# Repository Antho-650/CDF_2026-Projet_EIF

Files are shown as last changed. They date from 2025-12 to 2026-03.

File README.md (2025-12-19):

# CDF 2026 - Projet EIF

Dépôt officiel pour la participation à la Coupe de France de Robotique 2026.

## Documents et Suivi

Le suivi des achats (Excel/Google Sheets) et les documents administratifs sont sur le Google Drive du projet : https://drive.google.com/drive/u/1/folders/1xHnVBchuZF8TSyvHd5yfe0Ny8L7n_gqj

## Structure du dépôt

- **documents/** : Documents généraux du projet (spécifications, règlement, etc.)
- **robot_principal/** : Fichiers du robot principal
  - **electronique/** : Cartes électroniques (haut niveau, base mobile, actionneurs)
  - **mecanique/** : Conception mécanique (assemblage complet et sous-ensembles)
  - **code/** : Code embarqué (STM32) et code haut niveau (Raspberry Pi)
- **balises/** : Système de balises (électronique, code, mécanique)
- **pami_ninja/** : PAMI Ninja (électronique, mécanique, code)
- **pami_statique/** : PAMI Statique pour fin de match (électronique, mécanique, code)

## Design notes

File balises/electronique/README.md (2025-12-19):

# Balises - Électronique

Fichiers KiCad pour les cartes électroniques des balises de détection.

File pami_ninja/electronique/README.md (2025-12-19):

# PAMI Ninja - Électronique

Fichiers KiCad pour la carte électronique du PAMI Ninja.

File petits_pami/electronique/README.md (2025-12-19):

# PAMI Statique - Électronique

Fichiers KiCad pour la carte électronique du PAMI Statique (fin de match).

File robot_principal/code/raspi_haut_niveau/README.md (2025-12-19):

# Code Raspberry Pi - Haut Niveau

Code Python pour le Raspberry Pi (stratégie, intelligence artificielle, communication).

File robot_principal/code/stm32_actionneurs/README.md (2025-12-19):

# Code STM32 - Actionneurs

Code embarqué STM32CubeIDE pour le contrôle des actionneurs.

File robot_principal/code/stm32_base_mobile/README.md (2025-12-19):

# Code STM32 - Base Mobile

Code embarqué STM32CubeIDE pour le contrôle de la base mobile.

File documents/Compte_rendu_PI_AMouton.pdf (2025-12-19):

# Compte Rendu Projet Ingénieur

## Réalisation d’un robot pour la coupe de France de robotique

## Etudiant Ingénieur : Albin Mouton

## Tuteur de Projet : Xavier Redon

## Responsable UE Projet : Florian Chevalier

# Introduction

## La Compétition

La coupe de France de robotique est une compétition nationale qui, cette année, fête ses 30 ans.
Elle réunit une centaine d'équipes chaque année en mai, à la Roche-Sur-Yon.
Le règlement de la compétition est publié tous les ans en septembre. J’ai pu m’appuyer sur celui-ci lors de la rédaction de mon cahier des charges.
Les équipes doivent alors concevoir un robot de toute pièce, afin de remporter un maximum de points.
Les robots participent à des matchs en 1 contre 1. Deux équipes tentent en même temps de réaliser un maximum d’actions.
Le thème de cette année est “Coloniser Mars”. Les robots sont dans un scénario de “ferme spatiale” avec plusieurs objectifs :
- Récupérer des plantes, les mettre dans des cache-pots, et venir les trier dans des zones de dépôt ;
- Orienter des panneaux solaires ;
- Faire entrer en contact les PAMI avec les plantes récupérées ;
- Prédire le plus précisément son score.

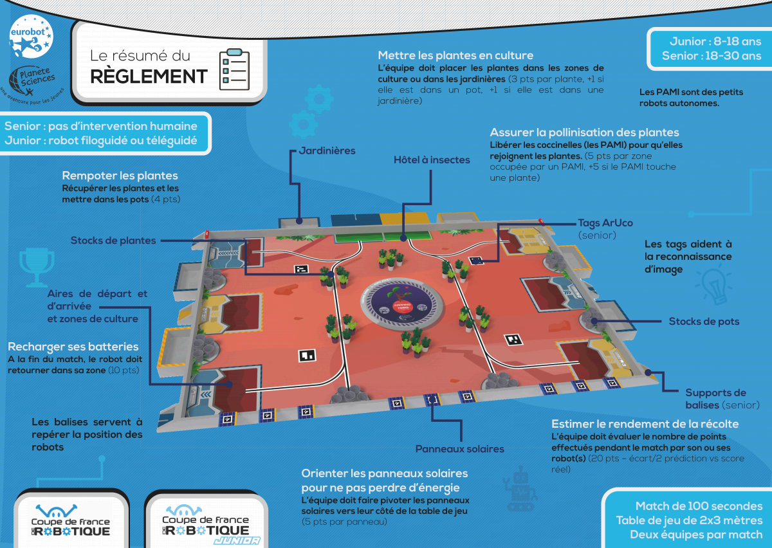
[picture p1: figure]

Figure 1. Illustration simplifiée du règlement

Les robots doivent respecter certaines règles :
- Être plus petit qu’un cube de 30x30x30 cm ;
- Etre autonome sur l’ensemble du temps de jeu (100 secondes) ;
- Démarrer en tirant une ficelle ;
- Ne pas entrer en contact avec le robot adverse, ou endommager le matériel de jeu ;
- Etre équipé d’un bouton d’arrêt d’urgence ;
- Les batteries doivent respecter des consignes de sécurité.

Sur place, les robots doivent d’abord passer 2 homologations, effectuer au maximum 5 matchs de placement, avant de potentiellement participer à l’arbre de tournoi de la phase finale.
Les 2 meilleures équipes obtiennent le droit de participer à la coupe d’Europe qui se déroule à la Roche sur Yon le même weekend.

## L’Équipe

Cette année, j’ai la chance de participer à la coupe de France de Robotique avec une dizaine d’élèves ingénieurs membres de Robotech. Le club de robotique de l’école, Robotech, a déjà participé à cette compétition l’année passée. La participation du Club après plusieurs années d’absence nous a permis de nous rendre compte du réel défi que représentait la coupe, de nous positionner face à nos adversaires et surtout d’évaluer nos choix de conception grâce à une mise en conditions réelle de notre robot.
C’est ainsi qu’aidé par le bureau du club de robotique de l’école, j’ai pu mettre en œuvre les leçons apprises l’an passé et tirer profit de la conception précédente de notre Robot.

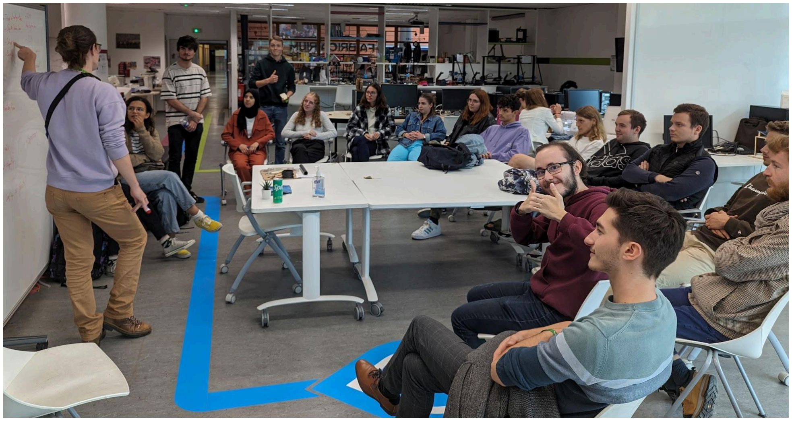
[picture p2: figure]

Figure 2. Réunion de présentation du projet aux membres du club

# Cahier des charges

Ci-dessous vous trouverez le cahier des charges initial commenté afin évaluer l’état d’avancement du projet.
( ✅ : objectif complété, ➖ objectif partiellement réalisé (avec un commentaire), ❌ objectif non-atteint)
- Conception du robot principal | ➖
- Conception/Intégration d’un ou plusieurs lecteurs RFID. (réorienté en IA)➖
■ Conception du nœud ROS2 de lecture du tag. | ✅
- Conception d’une base roulante | (Partiellement assemblée) | ➖
■ Base roulante dont la projection a un périmètre
est inférieure à 120 cm | ✅
■ Conception d’un contrôleur de moteur BLDC | ➖
- Asservi (capteur d’orientation magnétique)
en Field Orientation Control (FOC)
(Performance Insuffisante ) ➖
- Base STM32 | ✅
- Communication CAN, UART & USB | ✅
- Alimentation batterie Li-Po 6S | ✅
- Support de moteurs jusqu’à ~30A | ✅
■ Conception d’un système d'entraînement des roues par BLDC | ✅
- Conception d’actionneurs de saisie | ❌
■ Conception mécanique des actionneurs | (en cours) | ➖
■ Développement de nouveaux noeuds ROS2 adaptés aux nouveaux
actionneurs | ❌
- Correction de la carte mère actuelle du robot | ✅
■ Développement d’un driver pour permettre d’interfacer les IMU | ❌
- Amélioration du système de Path Planning | ❌
- Amélioration du système de calcul de points | ❌
- Conception des PAMI | ➖
- Conception d’une carte mère | ✅
■ Taille la plus petite possible ~25cm² | ✅
■ Contrôle de 2 moteurs DC | ✅
■ Des emplacements pour des vis afin que le PCB soit un châssis ✅
■ Des GPIO permettant une modularité sur les actionneurs | ✅
■ Capteurs de couleur pour permettre un suivi de ligne | ✅
■ Bouton d’arrêt d’urgence (besoin de modifier la carte d’extension pour
soutien mécanique) | ➖
■ Communication Radio (bandes 2.4 GHz & 5 GHz proscrites car
surchargées, donc probablement du sub-GHz ) | ✅
- Conception d’une clé USB pour interfacer les PAMI via cette bande radio
choisie | ✅
- Communication avec une tour de supervision selon des objectifs transmis par
le robot principal | (en cours) | ➖

# Cahier des spécifications

Ci-dessous se trouve le cahier des spécifications communiqué au tuteur.

## Description des éléments

### Tour de supervision

La tour de supervision est placée dans une zone dédiée du terrain. Elle peut être suffisamment haute pour permettre à une caméra d'y être installée. Cette caméra sera une caméra 4K avec un FOV de 110° pour voir l’ensemble du terrain.
Sur cette tour se trouve également un micro-ordinateur (NVidia Jetson), venant interpréter les valeurs de la caméra à l’aide de la bibliothèque OpenCV.
ROS2 sera également installé pour permettre de débugger le robot principal et la tour simultanément si tous sont sur un même réseau local.

### Carte de contrôle de moteur BLDC

Basé sur un STM32F303 et un DRV8323, le contrôleur peut commuter jusqu'à 36V à ~30A pour venir alimenter un moteur à courant continu sans balai (BLDC).
Le PCB est un PCB 4 couches (70 um - 17.5 um - 17.5 um - 70 um)
Il dispose d'un port USB, de 2 ports série et d'un port CAN pour venir changer la consigne. Un encodeur (incrémental ou positionnel) peut venir être connecté. Le moteur pourra être asservi en vitesse ou en position.
La carte sera auto-alimentée (générera ses rails 5V et 3.3V) à partir de la tension de la batterie.

Un identifiant peut être programmé dans la mémoire non volatile via le port USB. Cet identifiant définit les adresses à lire sur le bus CAN.

Un nœud ROS2 doit être écrit pour communiquer les consignes de vitesse avec les contrôleurs via le bus CAN. Celui-ci traduit également une commande de vitesse dans un repère orthonormé en les vitesses équivalentes des 3 moteurs placés en Triangle.

Le firmware de la carte mère doit être modifié pour permettre une communication CAN.

### Encodeur absolu magnétique

Cette carte est un simple support pour l'encodeur magnétique MT6701, capable de communiquer en I2C ou en incrémental (UVW). Un connecteur JST-SH permettra de l’interfacer.

Le PCB est un PCB 2 couches (35 um - 35 um, sans contrôle d’impédance des lignes)

### Clé USB Radio

Pour communiquer avec les PAMI et ne pas modifier en profondeur la carte mère du robot principal, un STM32 vient interfacer un port USB-A et une puce CC1101 pour permettre à un ordinateur la communication 865 MHz. Un connecteur d’antenne SMA permettra de pouvoir expérimenter avec différentes antennes.

Le PCB est un PCB 4 couches (35 um - 17.5 um - 17.5 um - 35 um)

Le STM32 apparaît comme un port série virtuel, les paquets émis en UART seront émis en radio et vice-versa.
Cette clé servira également sur la tour de supervision

### PAMI

La taille du PAMI doit être inférieure à 8x8x8cm.

Le PCB principal est un PCB 4 couches (35 um - 17.5 um - 17.5 um - 35 um)
Les PCB des capteurs de distance et d’extension seront des PCB 2 couches (35 um - 35 um, sans contrôle d’impédance)

Basé sur un STM32F103, les PAMI sont dotés de 2 contrôleurs de moteurs DRV8837, un contrôleur de charge de batterie Li-Po/Li-Ion (MCP73831), un buck boost 2.5V-6V -> 3.3V (TPS63051), et un accéléromètre gyroscope (LSM6DS3). Il peut être alimenté par des piles AA ou une batterie.
3 sorties de puissance sont disponibles (ex : pour alimenter un électro-aimant directement avec la batterie).

Un second PCB sert également à venir intégrer des connecteurs d'extension, ainsi qu’un tag ARUCO, qui pourront être lu par une caméra de supervision pour obtenir la position du PAMI.

Trois PCB supportant des capteurs de distance VL53L3 seront soudés verticalement entre le PCB principal et le PCB secondaire.

Les PAMI sont dépendants des informations de positionnement qui leur seront envoyées via la tour de supervision. Une fois que le robot principal aura démarré, un signal leur sera envoyé. Cela déclenche un timer de 90 secondes, qui, une fois dépassé, démarre le programme de déplacement des PAMI. Les PAMi vont à un objectif aux coordonnées prédéfinies en se basant sur les informations de position renvoyées par la caméra, mais peuvent s’arrêter si un obstacle est détecté devant eux.

# Organisation et gestion de projet

## Communication avec le tuteur projet

Pour permettre un suivi du projet par mon tuteur, un Wiki a été mis en place. Dans celui-ci j’ai pu documenter toutes mes avancées, ainsi que donner les premières documentations techniques.
Ce wiki est disponible ici (https://projets-se.plil.fr/mediawiki/index.php/SE5_2023/2024_P2) Ce système de documentation m’a permis de rédiger les premières documentations, poser le contexte, mais aussi d’évaluer la progression hebdomadaire de mon projet.

J’ai également pu rentrer en contact avec M. Redon afin de lui soumettre les problématiques que j’ai pu rencontrer :
- Du matériel a pu être commandé afin de corriger certaines cartes ;
- Nous avons pu discuter d’algorithmes de commande de moteur afin d’optimiser le contrôle de celui-ci ;
- J’ai pu exprimer et formaliser les points méritaient son attention, ce qui m’a permis de synthétiser les problèmes pour qu’ensemble nous trouvions des solutions.

## Gestion financière

Le matériel a été acheté par la trésorerie du club. Un rapport complet des dépenses a été effectué. Cependant, des fonds ont dû être levés pour financer de nouvelles générations de PCB. Pour cela, j’ai pu travailler en Freelance pour le club auprès d’un ancien étudiant de Polytech Lille.
J’ai pu concevoir une carte permettant de contrôler un moteur pas à pas via un port USB, ainsi que diverses entrées sorties. Cette carte dispose également d’un Hub USB pour permettre de venir brancher une caméra et d’être reconnue par le PC hôte. La carte est contrôlée en GCode, avec la même bibliothèque que j’ai écrite pour les projets.
Cela a permis de ne pas faire perdre d’argent au club tout en finançant le projet de la coupe de France de Robotique.

## Gestion d’équipe

Dans le cadre du projet, j’ai été accompagné par les membres de Robotech, club de robotique de Polytech-Lille. En ma qualité de chef de projet, j’ai pu gérer cette équipe pour atteindre les objectifs listés plus haut dans la partie technique.
Pour se faire, j’ai pu organiser des réunions d’avancement hebdomadaires (tous les mercredis midis), ainsi que des séances de travail (tous les mercredis soir). Dans ces séances, j’étais disponible pour investiguer les obstacles qu’ils rencontraient, former les nouveaux membres, débattre et trancher sur les solutions techniques proposées.

J’ai pu mettre en place différents outils afin d’organiser nos travaux :
- Un serveur discord, permettant la discussion organisée par salons tournés vers des sous parties du projets. Cela avait pour but de laisser une trace simple et informelle des échanges, ainsi que de pouvoir noter les éléments de réponses et astuces qui n’auraient pas eu place dans ce rapport
- Un répertoire Gitlab, pour permettre la mise en commun de code, car la perte de travaux est monnaie courante, comme les membres utilisent leur matériel personnel, et qu’il est pertinent de pouvoir travailler à plusieurs sur un même sous-ensemble du projet.
- Une équipe Fusion-360, pour permettre aux élèves ingénieurs en spécialité mécanique de travailler en commun, d’exporter la nomenclature de tout ou partie du projet, et de faire du versioning sur des pièces ou des assemblages ;
- Un ordinateur de test dans la même configuration que le robot, afin de tester dans des conditions proches, le code qui a pu être développé ;
- Des disques dur bootable & live, sous Linux (Ubuntu 22.04) où ROS2 est installé, pour pouvoir permettre un développement aux personnes sous des machines Windows.

J’ai pu gérer la motivation d’une équipe, encourager l’évolution de chacun, et conseiller leurs décisions afin qu’ils puissent obtenir un résultat tangible.

J’ai également défini une politique d’évaluation de la valeur du temps de chacun passé sur une tâche. En effet, j’ai imposé à chaque membre de se définir un équivalent coût-horaire. Si, pour mettre en place une solution, une option permettait d’économiser N heures de travail coûtait moins que N*(coût horaire auto-défini pour la personne), alors nous investissions pour économiser du temps.
Cette politique est due au fait que le temps disponible de chacun par semaine est réduit (au minimum 2h, au maximum ~8h). De plus, cela a permis à certains membres d’explorer de nouveaux outils.

## Gestion du temps

On peut comparer le diagramme de Gantt initial et le diagramme actualisé.

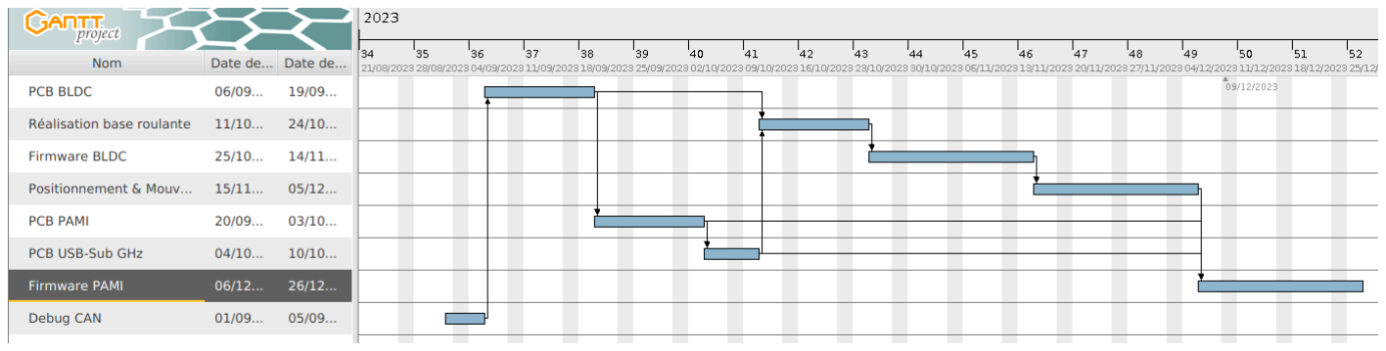
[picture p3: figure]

Figure 3. Gantt prévisionnel

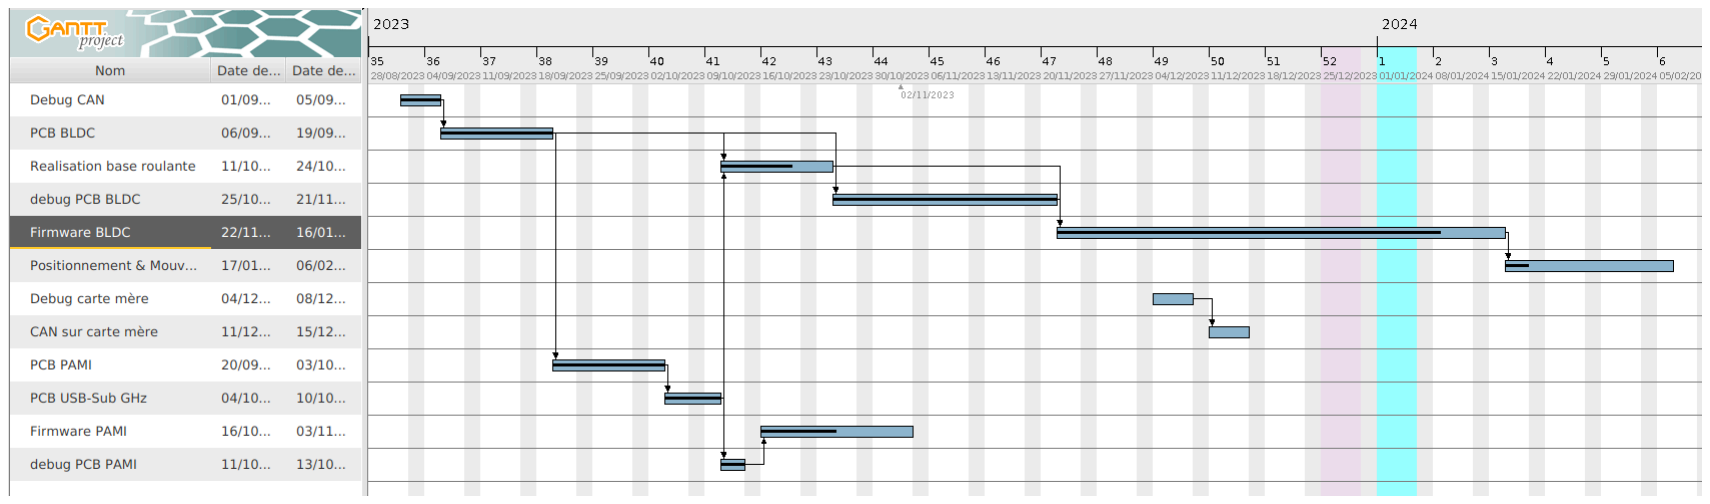
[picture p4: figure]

Figure 4. Gantt mis à jour

J’ai pris plus de temps qu’estimé à cause de problèmes techniques rencontrés. En effet, j’ai fait des erreurs sur les cartes qui m’ont pris du temps. Ces périodes de debug (que j’ai rajouté) m’ont fait perdre du temps. Suite à des problèmes de santé, je n’ai pas pu consacrer la semaine 01 de 2024, ce qui m’a également retardé.

# Carte de Contrôle moteur

## Contexte général

### La Coupe de France de Robotique 2023

Cependant, au cours du projet, nous avons réalisé que la motorisation de notre robot était insuffisante. Elle était basée sur des moteurs à courant continu avec balais (Moteurs DC), qui, par le biais de réducteurs, venaient faire tourner des roues Mecanum.
Cette architecture permettait un déplacement latéral du robot, mais a pu engendrer certains problèmes :
- 4 roues Mecanum placées comme sur une voiture sont requises.
- Pour que ces 4 roues soient en contact simultanément avec le sol, il faut un système de suspension :
■ Trop encombrant
■ Trop complexe (Il faut éviter autant de pièce possible en micromécanique)
■ Trop cher (Plusieurs centaines d’euros)
- Les 4 roues, avec leur réducteur réduisent grandement la surface au sol disponible pour les actionneurs. En effet, seule la moitié de cette surface permettait l’installation d’un bras manipulateur.
- Les moteurs DC disponibles dans le commerce, de petite taille, tournent souvent très (trop) vite mais développent un couple très faible. Un réducteur important est nécessaire (environ 1:200)
- Réducteur Planétaire : doit être réalisé sur mesure (très cher)
- Réducteur à vis : peu volumineux, abordable, et non réversible, mais souvent fragile (plusieurs casses le jour de la compétition)
- Réducteur à roue dentées : Plus volumineux, mais fragile, difficile à se procurer
- Réducteur à poulie : sur mesure, mais peut être réalisé au sein de l’école : chronophage
- Complexité de câblage
- La carte de contrôle de moteur DC faisait 10x10cm
- Elle supportait 6 moteurs avec leurs encodeurs (soit 6x(2+4) câbles) De plus, nous avons constaté que notre configuration (moteur DC) n’était pas utilisée par les équipes qui performaient le mieux.

## Hardware

### Choix de composants

Le coeur de la carte est un STM32F303BT
Celui-ci a été choisi de par :
- Son unité de calcul flottant : capable de faires des opération mathématiques sur des nombres à virgules, important pour pouvoir faire des calculs de PID ;
- Sa connectivité USB & CAN, la première pour pouvoir débugger et la deuxième pour la simplicité de câblage ;
- Les autres cartes du robot utilisent également des STM32. Toutes les fonctions implémentées sur un projet peuvent être portées sur un autre (par exemple le Parser GCode est la même bibliothèque que j’ai écrite pour les cartes de contrôleur moteur DC & BLDC).

Ce microcontrôleur commute les 6 MOSFETs nécessaires au contrôle du moteur par le biais d’un contrôleur DRV8323 de chez Texas Instruments.
Il inclut :
- Des amplificateurs pour la mesure de courant ;
- Un mécanisme de “charge pump” pour commuter les MOSFETs à haute tension ;
- Différentes sécurités (sur-courant, sous-tension, sur-tension entre le drain et la source lors de la commutation, …).
Pour permettre un asservissement en position, un encodeur magnétique 14 bits peut être connecté via un port JST-SH8. Celui-ci s’interface en I2C (débit relativement bas), ainsi qu’en UVW (impulsions successives par cran, plus rapide que la communication I2C)

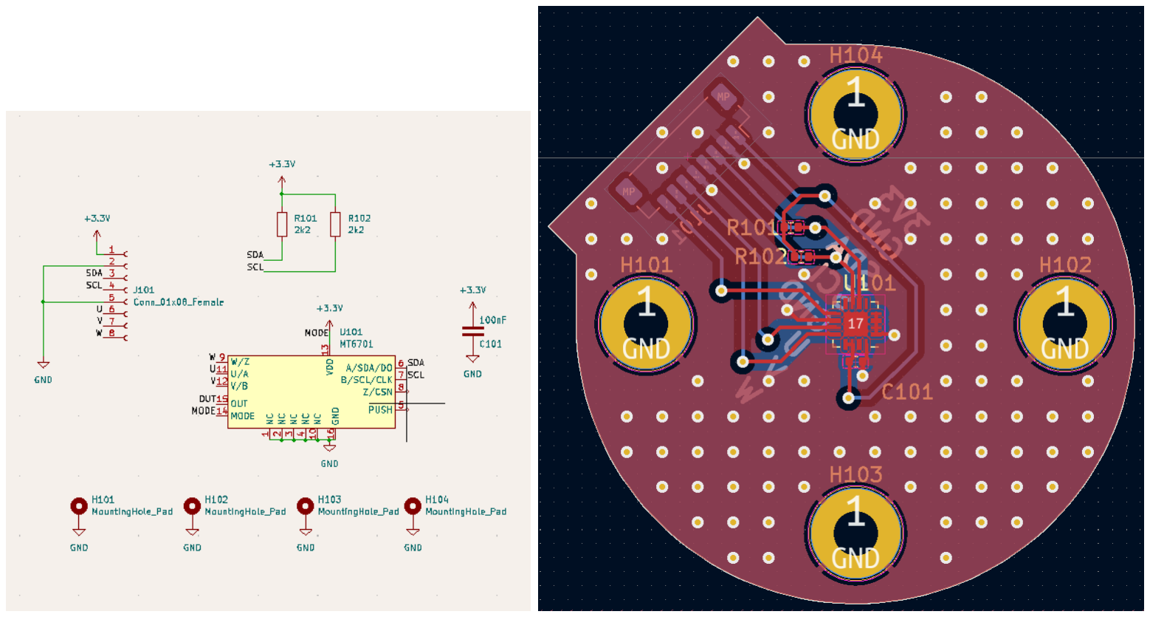
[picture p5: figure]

Figure 6. Schéma et PCB de l’encodeur

### Principe de fonctionnement

La contrôle peut se faire via port série (De nombreux ports série sont disponibles sur la carte mère) à 115200 bauds, 8b1n, ou port série émulé sur un port USB mini-B.

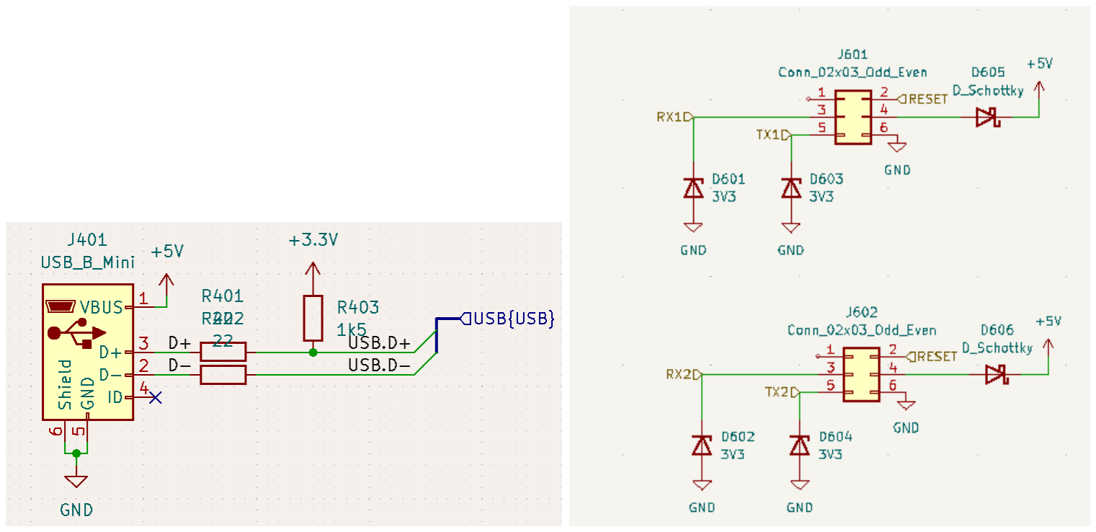
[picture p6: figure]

Figure 8. Port USB configuré en USB High Speed, et port série de communication

Il est également possible de communiquer avec la carte par bus CAN 10Mbps, cela permet de simplifier le câblage du robot en “chaînant” les contrôleurs. Le CAN (Signaux différentiels) est converti en CAN-TTL (TX & RX) par un SN65HVD230. Un cavalier peut être installé pour connecter une résistance de terminaison.

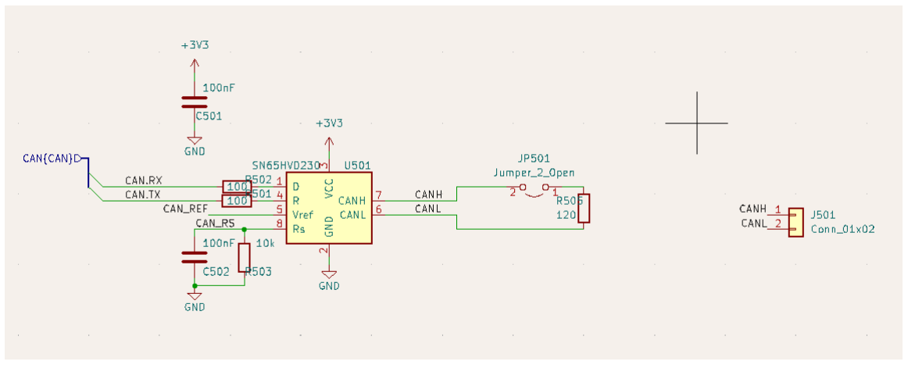
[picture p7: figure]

Figure 9. Transceiver CAN ⇔ CAN TTL

Un hacheur Buck convertit la tension de batterie de ~24V en 5V (commun avec le port USB), puis un Low Dropout Regulator (LDO) (AMS-1117) convertit le 5V en 3.3V pour les périphériques.

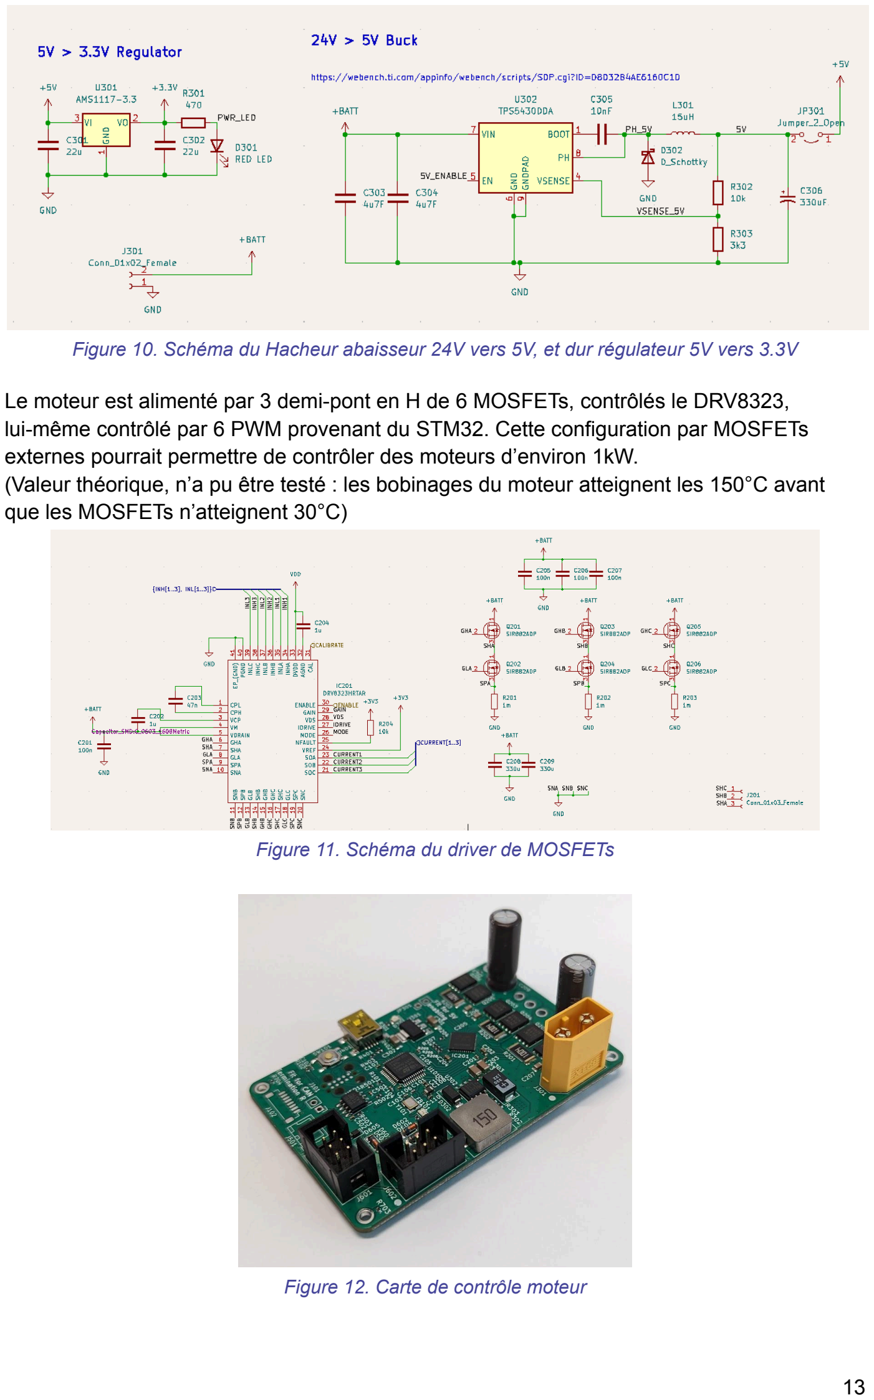
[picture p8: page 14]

Figure 10. Schéma du Hacheur abaisseur 24V vers 5V, et dur régulateur 5V vers 3.3V

Le moteur est alimenté par 3 demi-pont en H de 6 MOSFETs, contrôlés le DRV8323, lui-même contrôlé par 6 PWM provenant du STM32. Cette configuration par MOSFETs externes pourrait permettre de contrôler des moteurs d’environ 1kW.
(Valeur théorique, n’a pu être testé : les bobinages du moteur atteignent les 150°C avant que les MOSFETs n’atteignent 30°C)

Figure 11. Schéma du driver de MOSFETs

Figure 12. Carte de contrôle moteur

## Firmware

### Description générale

Dans le logiciel, un objet moteur est défini. Celui-ci contient tous les paramètres du contrôleur moteur. Au commencement, le moteur se place à la coordonnée 0°. Il prend une mesure par le biais de l’encodeur. C’est sa valeur de référence, son zéro-angulaire.
Par la suite, une boucle s'exécute à 10 kHz (fréquence constante assurée par FreeRTOS) :

Les paramètres du moteur peuvent être modifiés via les ports série ou l’interface CAN selon les commandes suivantes :
Adresse CAN | GCODE | Description
0x000 {vitesse} | G0 X{vitesse}; | Définit la vitesse angulaire du moteur (rad/s).
0x010 {vitesse} | G10 X; | Lit la vitesse actuelle du moteur (en rad/s)
0x001 {puissance} | G1 X{puissance}; | Puissance pour le moteur en condition normale (en %).
0x002 {duree} | G2 T{duree}; | Définit la durée du blocage en ms.
0x003 {puissance} | G3 X{puissance}; | Définit la puissance lors d’un blocage (en %)
0x004 {multiplicateur} | G4 X{multiplicateur} | Multiplicateur de la vitesse angulaire
0x005 {poles} | G5 X{poles} | Définit le nombre de paires de pôles du moteur
| G6 {ID} | Définit l’ID du contrôleur (paramètre stocké en Flash du moteur)
0x00A {kp} 0x00B {ki} 0x00C {kd} | G7 P{kp} I{kp} D{kd} | Définit les constantes du PID

Table 1. Protocoles de commande de la carte contrôleur de moteur L’adresse évoquée ci dessus doit être ajoutée à 256 * ID du contrôleur moteur. Ex : 0x010 = vitesse du moteur 0 ; 0x310 = vitesse du moteur 3 ;

### Principe de fonctionnement

Le moteur BLDC est alimenté par ses 3 phases (A, B & C) reliées en étoile comme suit. Chacune de ces phases doit être alimentée par une sinusoïde, mais toutes déphasées de 120°. Cet enchaînement de phase crée un champ magnétique tournant au stator du moteur. Le rotor, doté de 7 paires de pôles magnétiques (grâce à des aimants permanents) suivra ce chant tournant, entraînant la rotation.
Il est à noter que 7 tours du champ tournant sont nécessaires pour faire un tour mécanique de rotor.
Ainsi, pour faire varier la vitesse du moteur, on peut faire varier la période des sinusoïdes ABC. De même, pour faire varier le couple, on peut faire varier l’amplitude de ces sinusoïdes.

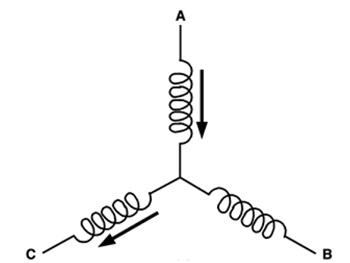
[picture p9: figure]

Figure 13. Modélisation du moteur BLDC

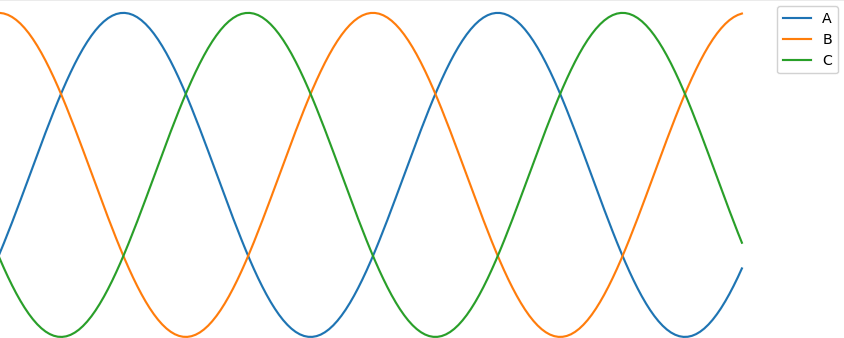
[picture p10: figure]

Figure 14. Sinusoïdes d’alimentation du moteur

L’intérêt de cette configuration est de pouvoir ajouter un encodeur absolu (souvent magnétique). Selon l’erreur angulaire entre la consigne et la valeur lue, nous pouvons moduler l’amplitude. Cela permet des rendements importants.

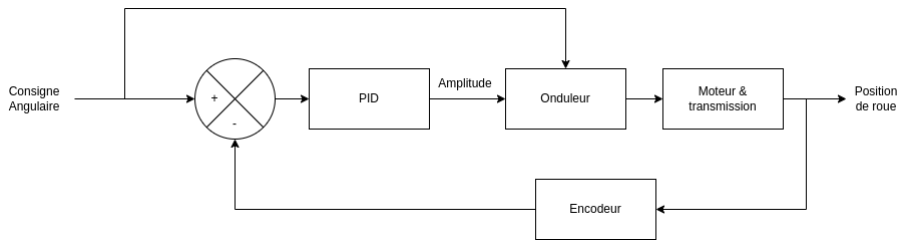
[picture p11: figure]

Figure 15. Boucle de régulation du moteur

### Code

Une structure C ‘moteur’ contient tous les paramètres pouvant être définis plus hauts.
Une fonction update est appelée périodiquement (10kHz) par FreeRTOS. Celle-ci vient lire la position de l’encodeur, incrémenter la consigne d’angle selon la vitesse, et effectuer les opérations de calcul décrites ci-dessus.
En résulte 3 valeurs flottantes (intensités à un instant t pour chacune des phases).
Ces valeurs sont converties en 6 PWM synchronisées (2 MOSFETs pour chaque phase, un amenant la ligne à la masse, un à la tension de batterie).

Une phase d’initialisation a lieu à l'alimentation du contrôleur : un champ à 0° est appliqué au moteur pendant 500ms pour lire la valeur de l’encodeur, et en faire le zéro. En effet, l’encodeur peut être déphasé de par la position de l’aimant/capteur sur le moteur.

Des interruptions sur les ports série viennent alimenter différents buffer pour être parsé lors de “temps libre” du contrôleur moteur. Une fois parsés, les paramètres sont injectés dans la structure ‘moteur’.

Un mécanisme d'anti blocage est nécessaire. Il semblerait que les paires de pôles ne soient pas homogénéiquement réparties sur le rotor du moteur. Cela pourrait être dû à des différences dans les performances des aimants permanents. Pour se faire, après un certain temps où le moteur ne bouge pas, la consigne angulaire est augmentée afin de “sauter” cette zone où les champs sont plus faibles.

Pour que chaque adresse sur le bus CAN soit unique malgré la présence de plusieurs contrôleurs moteurs, ces derniers ont tous un identifiant supposé unique, qui peut leur être programmé via interface série. Cet identifiant est stocké dans la flash de programme par le code lui-même, et chargé au boot.

## Software

### Contexte

La commande de vitesse se fait par le biais de la carte mère. Sur celle-ci se trouve ROS2, un Framework tourné vers la robotique. Nous pouvons reprendre toute la partie navigation de l’année précédente et venir modifier uniquement la partie qui était propre aux moteurs du précédent robot.

### Chaîne de transmission

Le Raspberry Pi Compute module 4 sur lequel tourne ROS2 n’a pas la possibilité de communiquer sur un bus CAN. C’est pourquoi un STM32F103 est présent sur la carte mère. Celui-ci dispose de plusieurs ports série, ainsi que d’un périphérique CAN-TTL.
Les deux communiquent via un port série et un port USB (ce dernier ne servant que pour la mise à jour du STM32).
On peut donc faire communiquer le Raspberry PI CM4 et les contrôleurs moteurs comme suit :

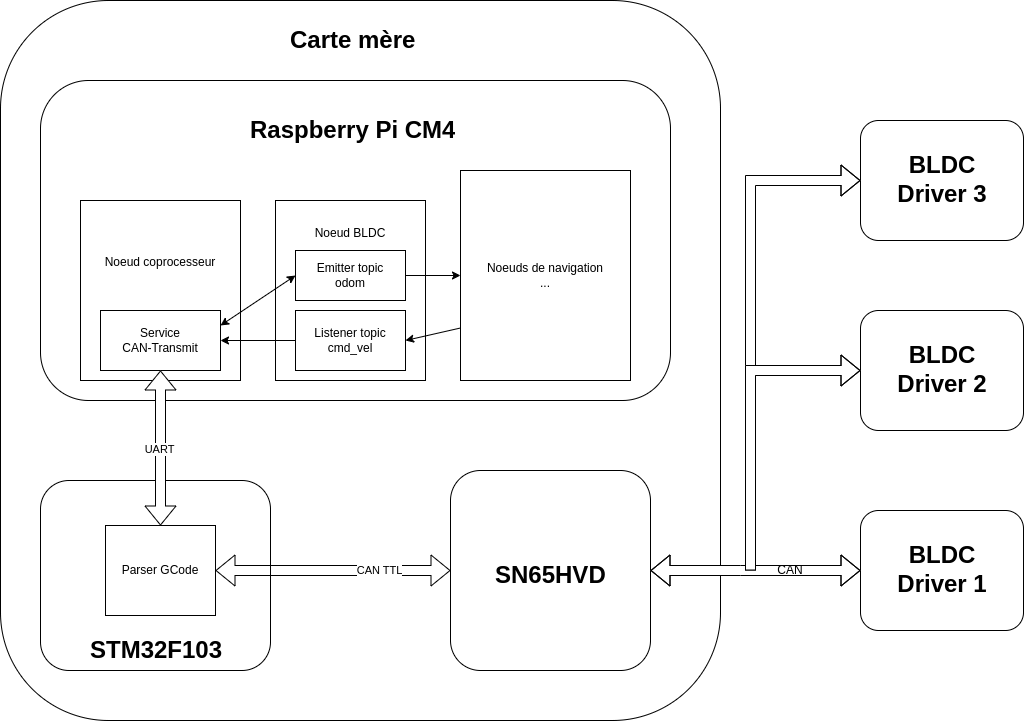
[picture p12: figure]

Figure 16. Schéma de la communication interne du robot, du micro-ordinateur vers les contrôleurs de moteur

### Noeuds ROS2

Un nœud permettant la communication entre le STM32 et le Raspberry Pi avait déjà été réalisé l’an passé. Il permettait, entre autres, de contrôler des entrées sorties, de lire la tension de la batterie et de contrôler la vitesse du ventilateur du raspberry. La
communication se fait par envoi de trames GCode. La solution à cela est d’implémenter une nouvelle commande GCode sur le STM32 qui envoie des messages sur le bus CAN.
GCODE | Description
G80 A{adresse} W{valeur}; | Écrit à l’adresse {adresse} la valeur {valeur} sur le bus CAN.
G81 A{adresse} I{id}; | Lit à l’adresse {adresse} sur le bus CAN, et renvoie un message : G81 V{valeur} I{id}; (l’id permet des lectures asynchrones).

Table 2. Commandes ajoutées au Coprocesseur STM32 de la carte mère

Ce nœud se chargeant de la liaison série offre déjà plusieurs services (fonctions pouvant être appelées par d’autres nœuds) pour les fonctions évoquées plus haut. De la même manière, 2 services ont été créés pour la lecture et l’écriture sur le bus CAN. (services appelés can_write, prenant un paramètre int_8[], les octets à écrire, et can_read, retournant un int_8[]).

Pour venir appeler ces services un nouveau noeud est créé :
Il vient écouter les messages sur le topic standard cmd_vel. Ces messages représentent une commande de vitesse dans un repère cartésien relatif au repère du robot.
Le noeud vient traduire cette consigne en vitesses pour les 3 moteurs

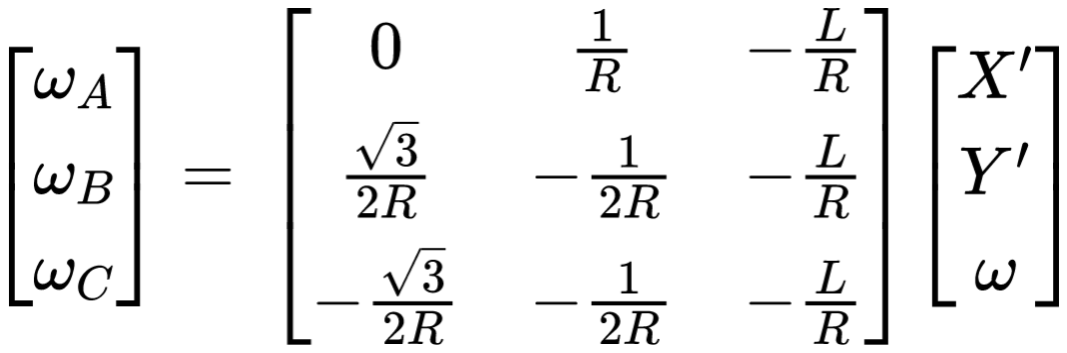
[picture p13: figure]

Figure 17. Relation entre consigne de vitesse cartésienne et vitesse des roues. Où :
ω est la vitesse de la roue N
N
L la distance entre la roue et le centre du robot
R le diamètre de la roue
Une fois les 3 vitesses des roues calculées, le service de transmission CAN est appelé 3 fois pour communiquer les vitesses au moteur.

Périodiquement, ce nœud vient lire les vitesses réelles des moteurs et évaluer sa propre odométrie, pour l’envoyer sur le topic standard ‘odom’.

Par la suite, des nœuds standard de ROS2 intégrant les algorithmes de pathfinding peuvent écouter et écrire sur ces topics pour commander le robot pour l’emmener à des coordonnées fixées.

## Mécanique

### Chaîne de transmission de puissance

Un réducteur par courroie a été conçu par Clovis Charrier (Méca 4).
Deux arbres en acier viennent maintenir une poulie chacun dans deux paliers découpés dans des plaques de PMMA.
Pour ajouter un encodeur, l’arbre du moteur a été modifié pour inclure un aimant néodyme diamétrique.
Le PCB de l’encodeur est fixé à l’arrière du support de moteur.

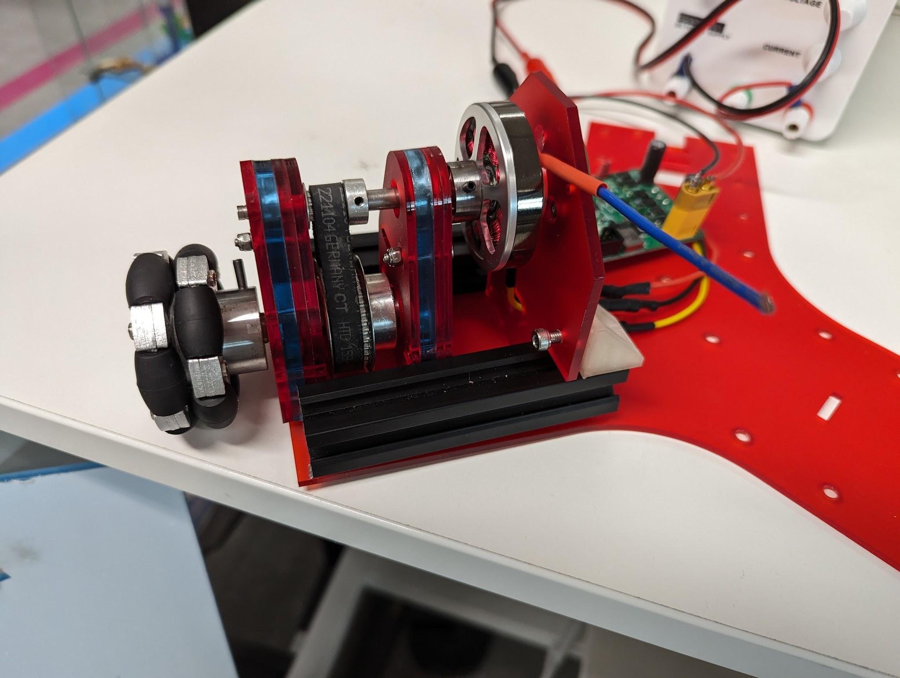
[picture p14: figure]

Figure 19. Chaîne de transmission de puissance mécanique.

# PAMI

## Contexte général

Les PAMI (Petits automates motorisés indépendants) sont des petits robots autonomes qui sont actifs dans le match à partir de la 90ème seconde et sur une durée de 10 secondes. Leur objectif est de rentrer en contact avec des objets rangés dans les zones de dépôt par le robot principal pour rapporter des points bonus.
Les règles de sécurité propres à tous les robots s’appliquent également aux PAMI :
Ils ne doivent pas entrer en contact avec un robot adverse, doivent disposer d’un bouton d’arrêt d’urgence, et doivent être déclenchés à la suite d’un tirage d’un câble (90 secondes après le déclenchement).
Puisqu’une équipe peut proposer jusqu’à 15 PAMIs, il est nécessaire que le prix de ceux-ci soit faible si l’on veut en proposer un maximum au cours de la compétition.

## Hardware

### Principe de fonctionnement

Le STM32F103 est le microcontrôleur au coeur du PAMI car celui-ci :
- est basse consommation, permettant plusieurs tests
- Dispose de nombreuses entrées sorties et périphériques :
- 1 port USB pour le débugger/mettre à jour facilement
- 2 ports I2C
- 1 port SPI
- De nombreuses interruptions
- Les programmes ayant été écrits sur d’autres plateformes du projet peuvent y être portés facilement.

Le contrôleur de moteur est un DRV8837 pour moteurs DC.
- Ils intègrent un pont en H pouvant commuter une charge jusqu’à 1.8A à de 0 à 11V ;
- Ils peuvent être mis en veille pour une consommation de ~30nA ;
- Ils sont peu onéreux (10cts pour 50 unités) ;
- Ils sont simples à interfacer (2 PWM) ;
- Ils utilisent des moteurs DC : existent en petits formats, en composant “off the shelf”, et avec des réducteurs, pour très peu cher (2€).

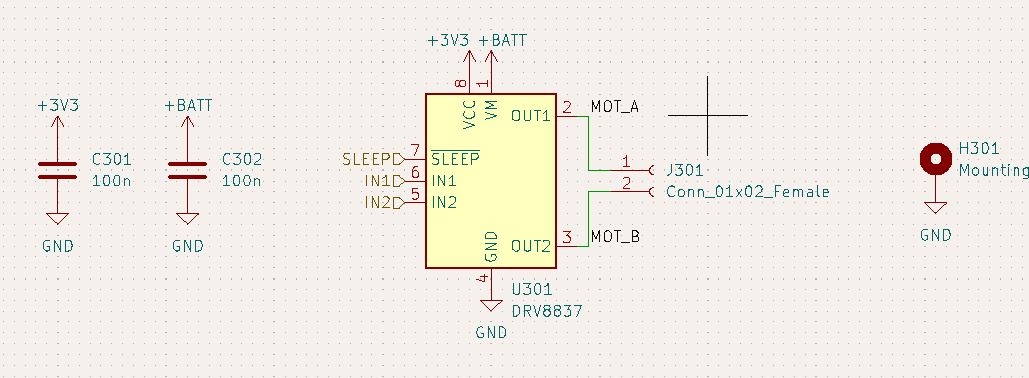
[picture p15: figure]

Figure 18. Schéma du pont en H commutant le moteur DC

Les capteurs de distance sont des VL53L1. Les avantages de ces capteurs sont qu’ils sont suffisamment immunes au bruit (très présent le jour de la compétition) et simples à interfacer en I2C. Jusqu’à 3 capteurs peuvent être placés sur un PAMI, mais pour des contraintes de coût, un seul est présent. Les GPIO d’évènements peuvent être reliées au STM32 par le biais du jumper JP101.
Ces cartes servent également à relier la carte principale à la carte d’extension.

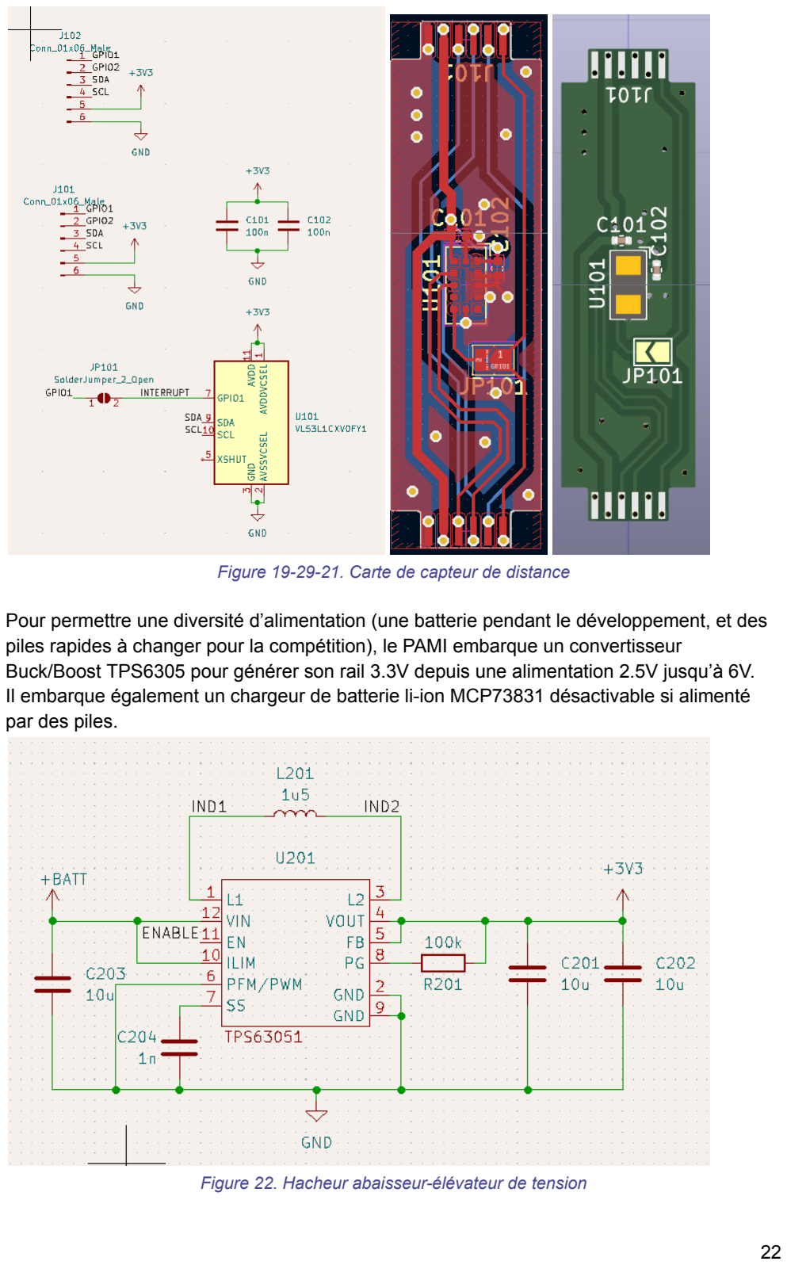
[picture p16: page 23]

Figure 19-29-21. Carte de capteur de distance

Pour permettre une diversité d’alimentation (une batterie pendant le développement, et des piles rapides à changer pour la compétition), le PAMI embarque un convertisseur Buck/Boost TPS6305 pour générer son rail 3.3V depuis une alimentation 2.5V jusqu’à 6V. Il embarque également un chargeur de batterie li-ion MCP73831 désactivable si alimenté par des piles.

Figure 22. Hacheur abaisseur-élévateur de tension

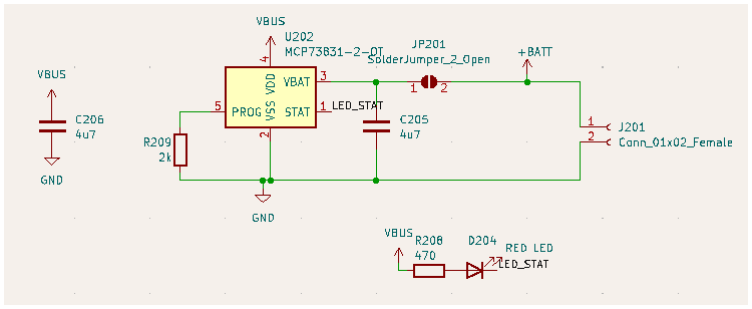
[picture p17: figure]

Figure 23. Circuit de charge de la batterie

En désactivant le TPS (pin ENABLE à la masse), la consommation à vide est de l’ordre du nanoampère. Pour activer le TPS et donc la carte, 3 méthodes existent :
- Appuyer sur un bouton poussoir
- Brancher le port USB
- Que le microcontrôleur maintient une GPIO à l’état haut.
- De ce fait, à l’allumage par un bouton, le microcontrôleur attend un certain temps puis de lui-même maintient le hacheur actif. Autrement, il s’éteindrait dès que le bouton serait relâché.

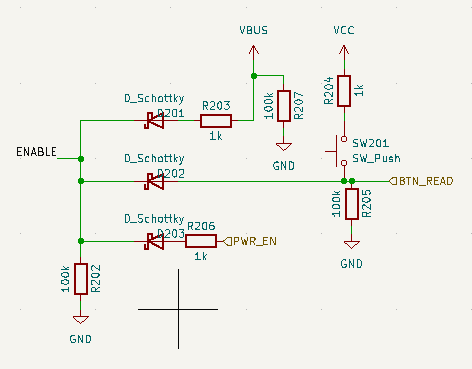
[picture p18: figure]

Figure 24. Schéma du ou logique à diode permettant d’activer le hacheur abaisseur-élévateur

Enfin, pour assurer la communication avec le robot principal, il embarque un CC1101 réglé pour communiquer à 815 MHz.
En effet, le Raspberry Pi de la carte principale peut communiquer en WiFi, cependant, la bande de fréquence 2.4GHz est surchargée lors de l’évènement. (ainsi que la bande 5.8GHz & 433 MHz).
Un réseau d’adaptation d’impédance est présent à la sortie de la puce, menant vers un connecteur SMA.

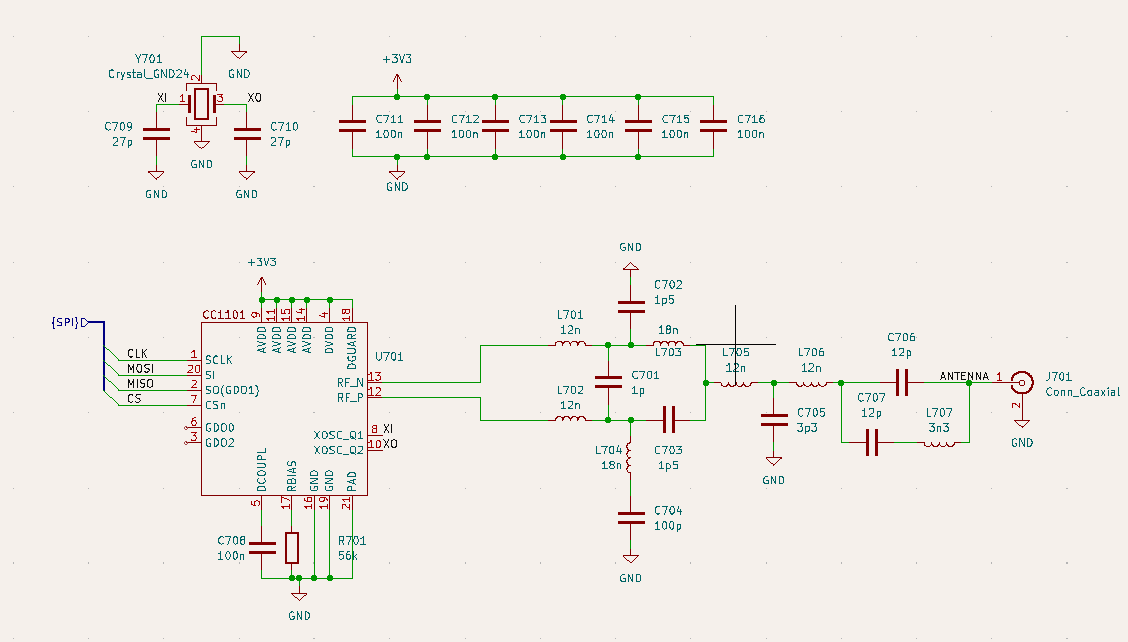
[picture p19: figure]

Figure 25. Circuit de communication Sub-GHz

### Mécanique

Pour réduire les coûts, le PCB est également le châssis du robot. Les moteurs viennent directement se visser sur le PCB. De même, une roue folle est installée à l’avant du robot dans le PCB. Les PCB des capteurs de distance servent à maintenir un PCB secondaire, qui ne sert qu’à maintenir le boîtier à piles et pour y mettre des connecteurs d’extension.
Il permet également d’accrocher un tag Aruco (QR code simplifié sans code correction d’erreur) qui sert à localiser le PAMI.

### Clé Radio

Une clé USB a été conçue pour pouvoir interfacer les PAMI avec n’importe quel ordinateur, y compris la carte mère du PAMI. Celle-ci dispose du même microcontrôleur et puce radio que les PAMI pour simplifier le développement.

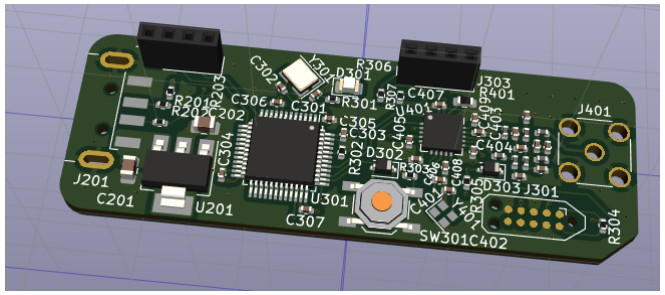
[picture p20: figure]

Figure 26. PCB de clé radio

## Firmware

Le STM32 est lui aussi programmé via le STM32CubeIDE. Il vient lire une consigne qui lui est fournie par le CC1101. Cette consigne lui est transmise par un paquet consistant de 3 octets : un premier donnant l’ID du PAMI à laquelle s’adresse le contrôleur, un octet pour la vitesse du moteur gauche, un octet pour la vitesse du moteur droit.
Cette vitesse est prohibée par la présence d’un obstacle détecté par le capteur de distance, ou par le bouton d’arrêt d’urgence.

De plus, à l’allumage, le STM32 fait clignoter une LED pendant 2 secondes pour indiquer son état, puis active la broche ENABLE de l’alimentation, pour se maintenir allumé. Cela permet au PAMI de s’éteindre lui-même en passant cette broche à l’état bas. Grâce à ça, un message peut être envoyé pour éteindre tous les PAMI à la fin de la manche, pour garantir que les robots ne se déplacent pas.

## Logiciel

Le logiciel a principalement été rédigé par les SE3 de Robotech : Victorien Détrez, Valentin Piroux & Ibrahim Tepeli

Sur le bord de l’aire de jeu se trouve une zone où une caméra peut être installée. Celle-ci vient reconnaître les tags Aruco propres à chacun des PAMI via un script python et la librairie openCV. Une transformation pour corriger l’effet de Fisheye de la caméra et une transformation affine vient corriger l’image. Une fois le code du tag Aruco reconnu, le script guide les Pami en les alignant vers leurs cibles et en les faisant avancer. Ces informations sont envoyées via la clé USB radio, qui se présente comme un port série

A l’avenir, il serait pertinent que le robot principal communique les objectifs à la tour d’observation pour que les PAMIs n’aillent qu'à des endroits où le robot principal a déposé des objectifs.

Cette reconnaissance des tags Aruco sert également pour détecter l’orientation des panneaux solaires (éléments à venir orienter)

# Logiciel Divers

## Reconnaissance d’images

Le logiciel de cette partie a principalement été rédigé par Benjamin Cart, SE3 de Robotech.

Un des éléments initiaux du cahier des charges était la reconnaissance des pots de plantes-objectifs. En effet, les plantes à récupérer peuvent être de deux types : plante faible (pot blanc) ou plante forte (pot violet). Initialement, nous envisagions d’utiliser un lecteur NFC afin de différencier ces deux types. Cependant, nous avons pivoté vers une méthode basée sur l’IA pour reconnaître les différentes plantes, et axer le préhenseur vers celles-ci.

Nous utilisons le modèle YoloV8 qui a déjà, parmi les éléments qu’il est capable de prédire, les plantes que nous devons récupérer. Ce modèle nous donne les “bounding boxes” des plantes dans l’image (sorte de cadre autour de l’objet). De ces coordonnées nous pouvons aller échantillonner la partie basse pour chercher une couleur (soit violet soit blanc), et traduire ces coordinées dans le repère de l’image en orientation pour notre robot.

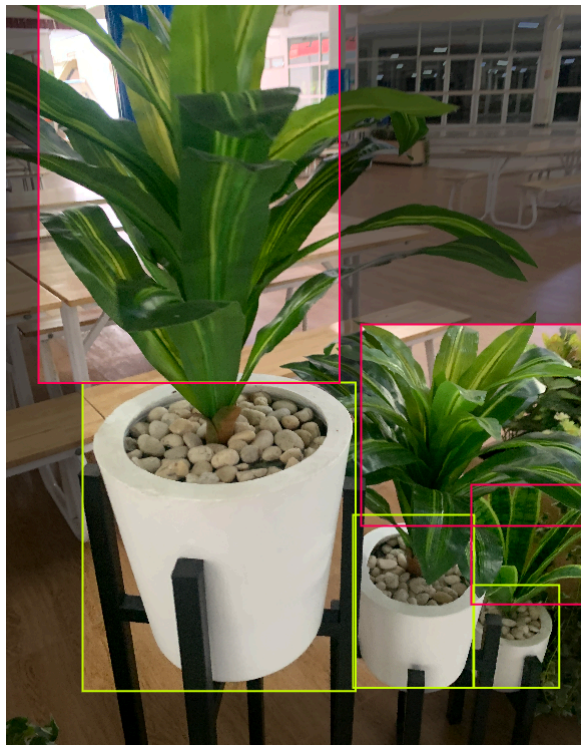
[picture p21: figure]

Figure 27. Démonstration du modèle de reconnaissance des plantes

## Détection de bordure

Le logiciel de cette partie a principalement été rédigé par Rémi Giner, SE3 de Robotech.

Trois capteurs 3D sipeed A010 seront installés sur le robot. Ils renvoient une image de 100 par 100 pixels, indiquant non pas la couleur d’un élément mais sa distance.

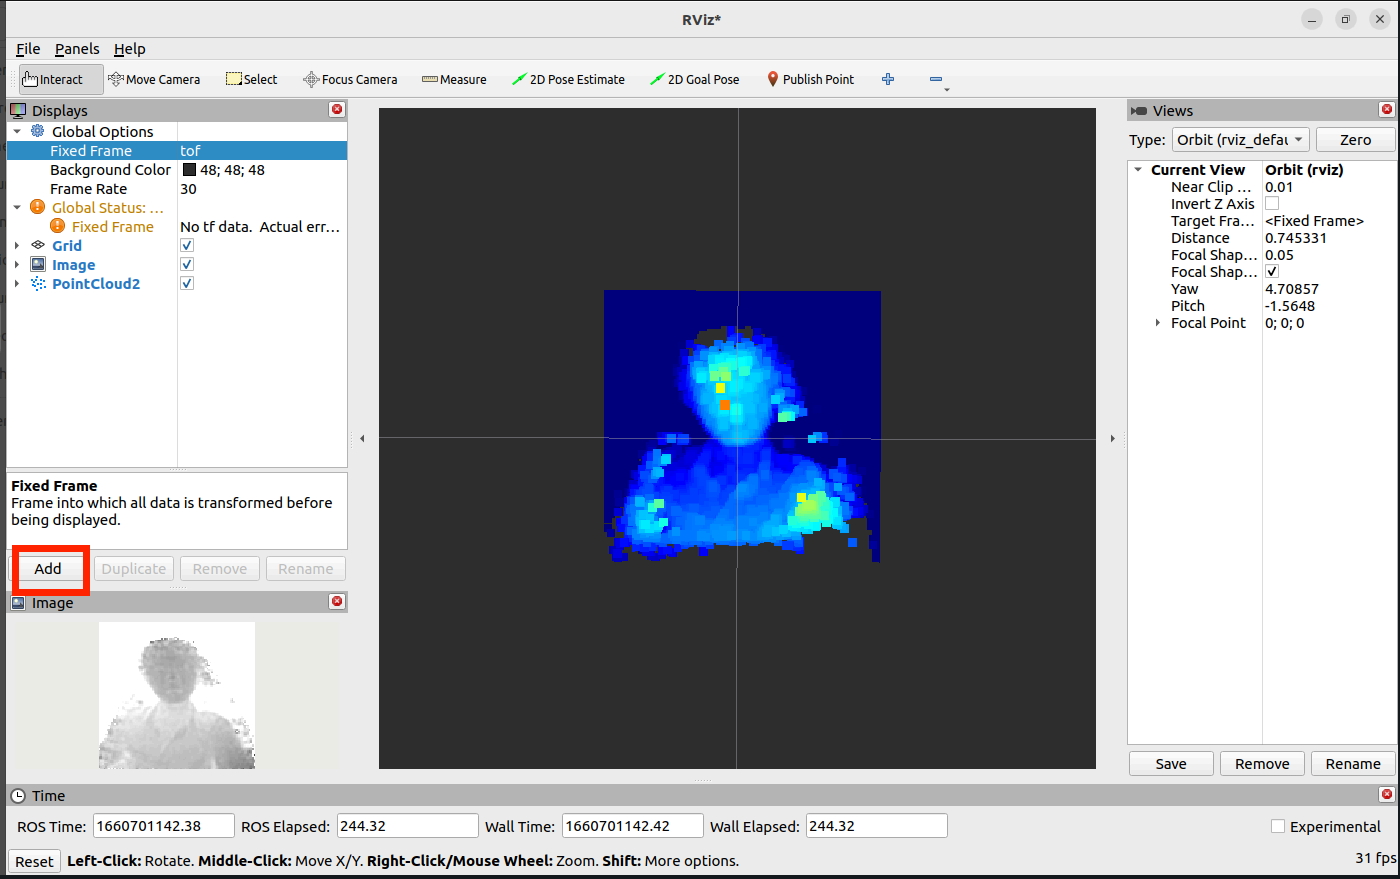
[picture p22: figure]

Figure 28. Données retournées par le capteur 3D

Nous utilisons cependant des techniques conventionnelles d’analyse d’image ( Détection de Canny et algorithme de Hough) pour détecter les bordures du terrain. A partir des angles & des distances des bordures relatifs au robot, nous pouvons estimer une position de celui-ci.

## Analyse et résolution de problèmes

### Driver de MOSFETs en erreur

Une source de mon retard a été le diagnostic de la carte de contrôle des moteurs BLDC. J’ai longtemps eu du mal à commuter les phases du moteur, car le contrôleur de MOSFETs DRV8323 rapportait une erreur.
Cela se traduit par une impulsion sur la broche de diagnostic lors de la commutation.
J’ai tout d’abord changé les résistances de configuration, afin d'augmenter la tolérance du contrôleur moteur sur ses sécurités, jusqu’à les désactiver.
Cela n’ayant pas suffi j’ai pu observer que seuls les MOSFETs reliant la phase à la masse déclenchent cette erreur, et que l’erreur apparaissait 4µs après la consigne émanant du STM32.
Suite à des échanges avec des ingénieurs de Texas Instruments, et par analyse du diagramme du circuit de protection, j’ai pu constater que ma résistance de mesure de courant était mal dimensionnée, et empêchait la mise à la masse du drain du MOSFET. En effet, suite à une erreur dans la nomenclature, la résistance de Shunt R n’était pas
SENSE
de 1m Ohm mais 1M Ohm.

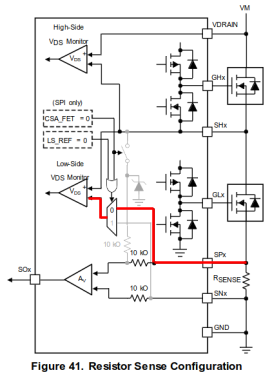
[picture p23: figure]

Figure 29. Schéma du fonctionnement de la fonction de détection de circuit ouvert à VDS

### Blocage moteur

Lors du développement du moteur, j’ai rencontré des blocages. Lorsque le moteur est contrôlé en boucle ouverte (consigne angulaire qui s’incrémente de façon constante, sans lecture du capteur), le moteur tourne correctement, même à faible vitesse.
Lorsqu’il est placé en boucle fermée (lire la position du moteur via l’encodeur, et incrémenter cet angle par une constante), le moteur venait se bloquer.
Cela peut s’expliquer par le fait qu’avec un incrément trop faible, ou pointant vers l’écart entre deux aimants empêche le rotor de tourner.
C’est pour ça que j’ai dû mettre en place un anti-blocage dans le code.

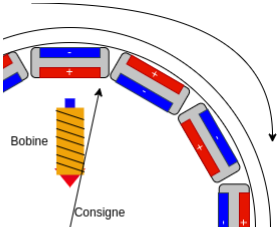
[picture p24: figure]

Figure 30. Schéma du blocage moteur : la consigne entraîne la bobine vers une zone entre 2 aimants permanents.

Avant de découvrir cette erreur, j’ai pu constater que les différentes PWM que j’utilisais pour contrôler le driver de MOSFET n’étaient pas synchronisées, car elles utilisaient des Timer différents. Cela causait des moments où le moteur était mal-alimenté.
J’ai pu trouver ce problème en modifiant le moteur pour avoir accès au point central du moteur. J’ai donc pu brancher un oscilloscope sur les 3 phases, et la référence sur ce point central, et constater le problème.

# Bilan du projet

## Discussion et Suite du projet

Les performances du contrôleur moteur ne sont pas encore au niveau attendu.
La technique de déblocage vient perturber la régulation de vitesse, causant des accoups, et une vitesse mesurée loin de la consigne initiale.
C’est pourquoi j’ai pu commander de nouveaux moteurs pensés pour le FOC pour tester si mes algorithmes sont pertinents et fonctionnels dans de meilleures conditions. Ces nouveaux moteurs sont conçus pour être utilisés dans des stabilisateurs pour de la vidéo, où un aucun accoup n’est tolérable.
Un contrôleur de moteur BLDC FOC de la marque ODrive dans le format qui nous intéresse vient d’être commercialisé ce mois-ci. J’ai pu en commander afin de tester si cette solution est pertinente dans notre cas.
Si cette solution ne marche pas, je pourrais adapter mes travaux de contrôleur de moteur pas à pas qui ont été éprouvés, pour en faire une carte de contrôle basée sur la même architecture que celle de moteur BLDC.

Je reprendrais également les travaux de l’équipe afin de finaliser le système de navigation. L'odométrie du robot de l’an dernier était mauvaise de par la nature des roues choisies. Ce système à 3 roues semble prometteur, tout comme le système de visualisation des bordures du terrain.

Une fois les financements reçus, je commanderai le terrain afin d’effectuer les prochains tests en conditions réelles.

Nous avons prévu de motoriser les actionneurs avec des moteurs pas à pas. Je porterai donc ma carte de contrôle de moteurs DC de l’an dernier pour les supporter, avec des drivers Trinamic TMC2208 (design déjà validé et éprouvé).

En conclusion et comme énoncé plus haut le projet n’est pas fini. Nous n’avons pas encore de base roulante éprouvée en février.
Cependant, de part l’aspect modulaire de la base de code de l’an dernier, nous pourrons très vite programmer le robot dès que la base roulante sera terminée.

## Leçons et Apprentissages

Ce projet m’a permis de mettre en pratique de nombreuses compétences : Techniques :
- Apprentissage à propos de la théorie des moteurs synchrones, chaîne de transmission, impédance et traitement du signal
- Conception de PCB à haut courant (aspect thermique et compatibilité électromagnétique)

Transversales :
- Travailler avec une nouvelle équipe
- Gestion du temps
- Résolution de problèmes
- Gestion de budget
- Définition d’un cahier des charges

Comportementales :
- Capacité à faire face à des imprévus/problèmes, réactivité
- Relation Client (dans le cadre de la mission « Free-lance »)
- Gestion d’équipe
- Capacité à former d’autres personnes à des outils (KiCAD, système Linux, ROS2)

Après cette expérience, je décide d'opter pour des technologies que je maîtrise parfaitement, afin de progresser de manière plus assurée dans mes projets de conception de contrôleurs de moteur.

Pour ce projet d'ingénierie, l'orientation vers le recherche plutôt que le développement à entraîné des retards pour l'équipe. Néanmoins, cette décision a constitué une opportunité précieuse d'apprentissage et de progrès technique.

J’aurais aimé pouvoir me concentrer davantage sur la gestion d’équipe, et mettre en place des rituels Agile comme vu en gestion de projet, et mettre en place un système de ticketing, tout en donnant des tâches plus petites à chaque individu pour les former point par point.

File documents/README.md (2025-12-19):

# Documents

Documents généraux du projet, spécifications techniques, règlement de la compétition, et autres fichiers de référence.

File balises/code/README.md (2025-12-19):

# Balises - Code

Code embarqué pour les balises (microcontrôleur).

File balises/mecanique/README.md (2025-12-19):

# Balises - Mécanique

Fichiers de conception mécanique pour le support des balises.

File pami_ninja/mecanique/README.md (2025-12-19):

# PAMI Ninja - Mécanique

Fichiers de conception mécanique pour le PAMI Ninja.

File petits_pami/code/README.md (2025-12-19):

# PAMI Statique - Code

Code embarqué pour le PAMI Statique (fin de match, microcontrôleur).

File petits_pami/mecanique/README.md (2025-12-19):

# PAMI Statique - Mécanique

Fichiers de conception mécanique pour le PAMI Statique (fin de match).

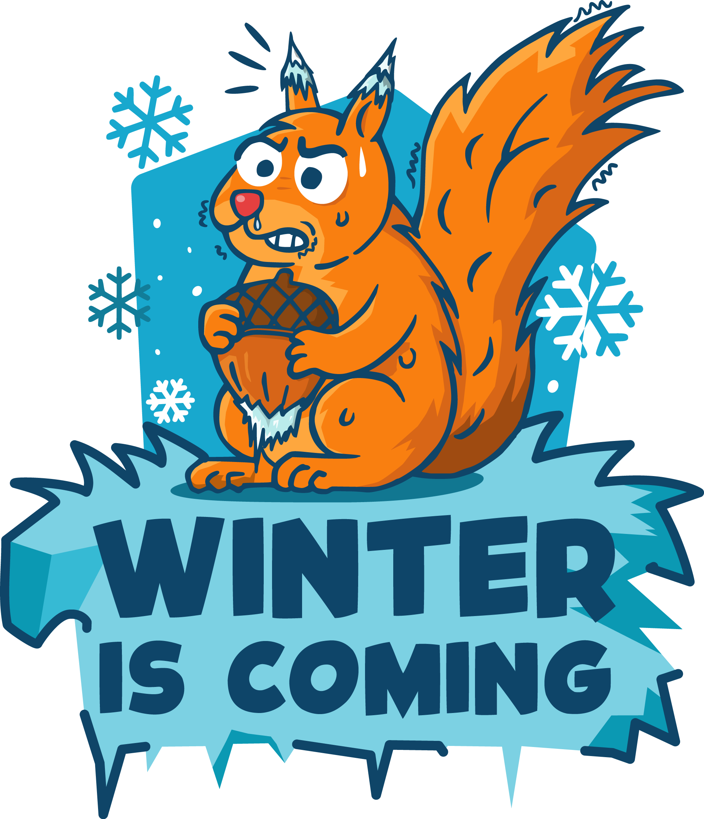
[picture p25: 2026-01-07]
documents/WINTER_IS_COMING.png

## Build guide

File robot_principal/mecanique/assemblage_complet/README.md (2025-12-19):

# Assemblage Complet

Fichiers de conception mécanique pour l'assemblage complet du robot principal.

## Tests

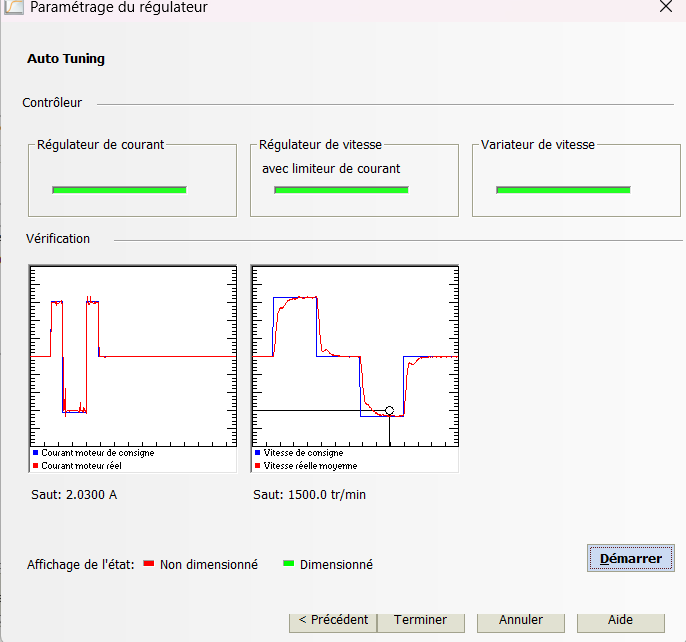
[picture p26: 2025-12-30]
robot_principal/electronique/carte_base_mobile/Moteur_maxon_test/courbe moteur maxon test reducteur 100.png

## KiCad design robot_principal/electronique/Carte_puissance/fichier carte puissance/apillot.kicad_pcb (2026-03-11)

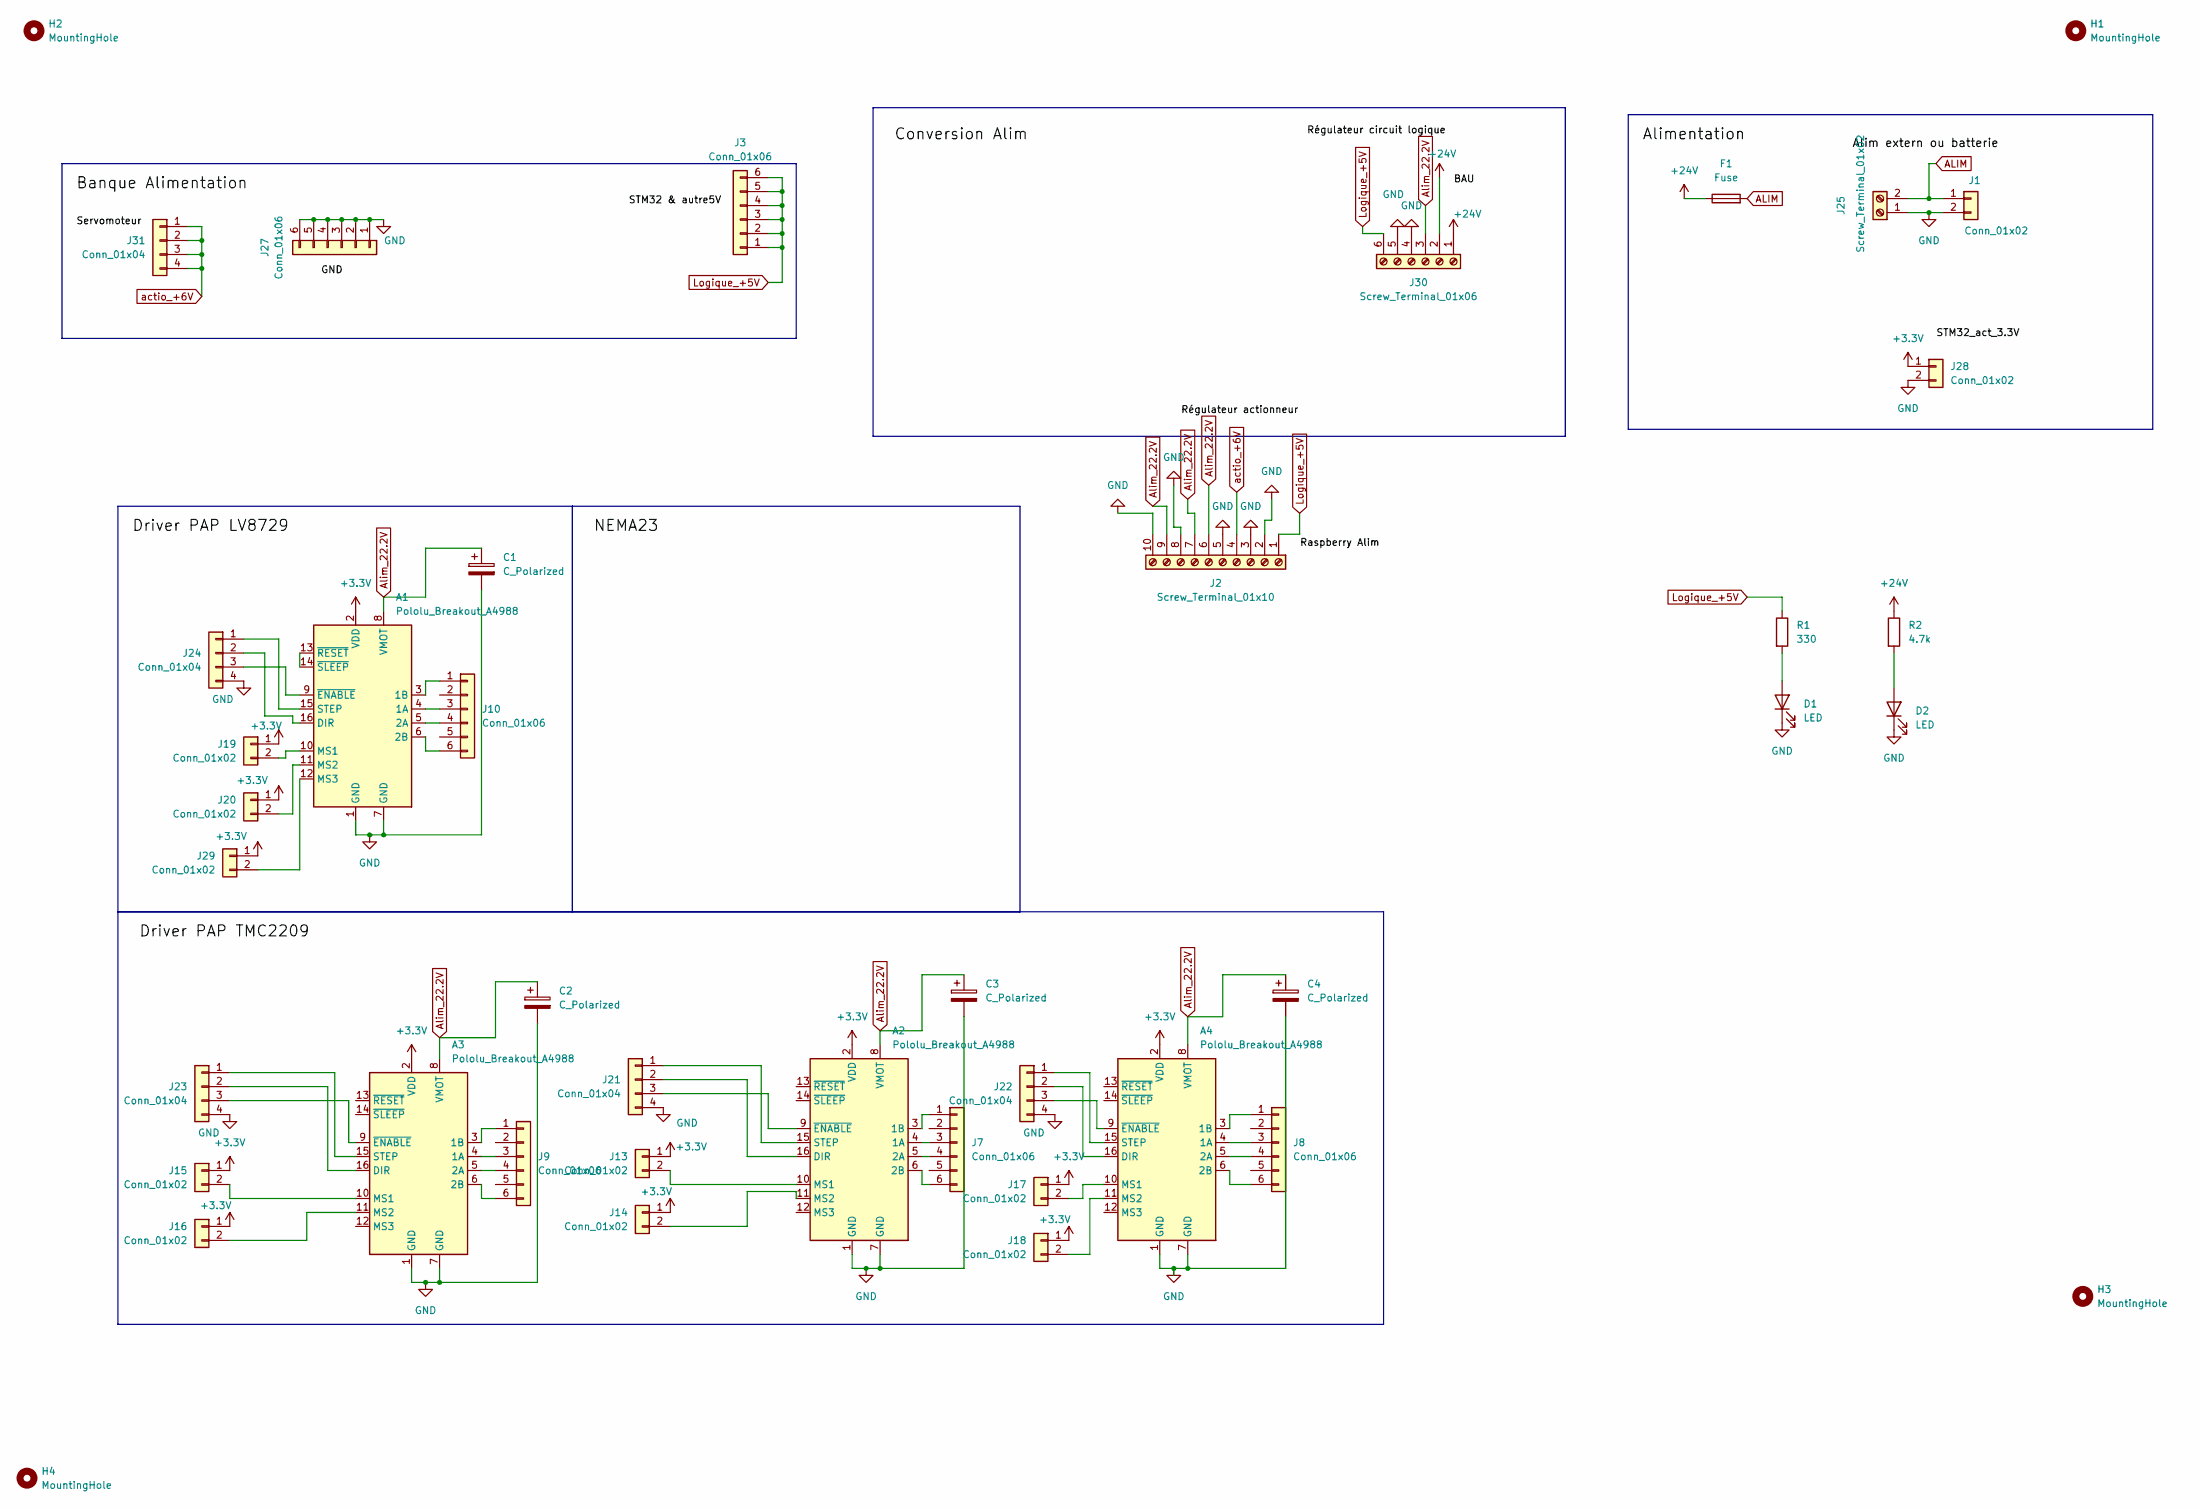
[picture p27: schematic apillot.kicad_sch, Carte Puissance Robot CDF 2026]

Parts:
A1, A2, A3, A4: Pololu_Breakout_A4988; Pololu_Breakout-16_15.2x20.3mm
C1, C2, C3, C4: C_Polarized; CP_Radial_D10.0mm_P5.00mm
D1, D2: LED; LED_D5.0mm
F1: Fuse; FuseHolder_Blade_ATO_Littelfuse_FLR_178.6165
H1, H2, H3, H4: MountingHole; MountingHole_3.2mm_M3
J1: Conn_01x02; AMASS_XT60-M_1x02_P7.20mm_Vertical
J2: Screw_Terminal_01x10; TerminalBlock_Phoenix_MKDS-1,5-10-5.08_1x10_P5.08mm_Horizon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
J3, J27: Conn_01x06; PinHeader_1x06_P2.54mm_Vertical
J7, J8, J9, J10: Conn_01x06; JST_XH_B6B-XH-A_1x06_P2.50mm_Vertical
J13, J14, J15, J16, J17, J18, J19, J20, J28, J29: Conn_01x02; PinHeader_1x02_P2.54mm_Vertical
J21, J22, J23, J24, J31: Conn_01x04; PinHeader_1x04_P2.54mm_Vertical
J25: Screw_Terminal_01x02; TerminalBlock_Phoenix_MKDS-1,5-2-5.08_1x02_P5.08mm_Horizont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
J30: Screw_Terminal_01x06; TerminalBlock_Phoenix_MKDS-1,5-6-5.08_1x06_P5.08mm_Horizont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
R1: 330; R_Axial_DIN0207_L6.3mm_D2.5mm_P10.16mm_Horizontal
R2: 4.7k; R_Axial_DIN0207_L6.3mm_D2.5mm_P10.16mm_Horizontal

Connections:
+3.3V: A1.2 (VDD), A2.2 (VDD), A3.2 (VDD), A4.2 (VDD), J13.1, J14.1, J15.1, J16.1, J17.1, J18.1, J19.1, J20.1, J28.1, J29.1
+24V: F1.1, J30.1, J30.2, R2.1
ALIM: F1.2, J1.1, J25.2
Alim_22.2V: A1.8 (VMOT), A2.8 (VMOT), A3.8 (VMOT), A4.8 (VMOT), C1.1, C2.1, C3.1, C4.1, J2.6, J2.7, J2.9, J30.3
GND: A1.1 (GND), A1.7 (GND), A2.1 (GND), A2.7 (GND), A3.1 (GND), A3.7 (GND), A4.1 (GND), A4.7 (GND), C1.2, C2.2, C3.2, C4.2, D1.1 (K), D2.1 (K), J1.2, J2.2, J2.3, J2.5, J2.8, J2.10, J21.4, J22.4, J23.4, J24.4, J25.1, J27.1, J27.2, J27.3, J27.4, J27.5, J27.6, J28.2, J30.4, J30.5
Logique_+5V: J2.1, J3.1, J3.2, J3.3, J3.4, J3.5, J3.6, J30.6, R1.1
unnamed: A1.4 (1A), J10.3
unnamed: A1.3 (1B), J10.1
unnamed: A1.5 (2A), J10.4
unnamed: A1.6 (2B), J10.6
unnamed: A1.16 (DIR), J24.2
unnamed: A1.10 (MS1), J19.2
unnamed: A1.11 (MS2), J20.2
unnamed: A1.12 (MS3), J29.2
unnamed: A1.15 (STEP), J24.1
unnamed: A1.9 (~ENABLE), J24.3
unnamed: A1.13 (~RESET), A1.14 (~SLEEP)
unnamed: A2.4 (1A), J7.3
unnamed: A2.3 (1B), J7.1
unnamed: A2.5 (2A), J7.4
unnamed: A2.6 (2B), J7.6
unnamed: A2.16 (DIR), J21.2
unnamed: A2.10 (MS1), J13.2
unnamed: A2.11 (MS2), J14.2
unnamed: A2.15 (STEP), J21.1
unnamed: A2.9 (~ENABLE), J21.3
unnamed: A3.4 (1A), J9.3
unnamed: A3.3 (1B), J9.1
unnamed: A3.5 (2A), J9.4
unnamed: A3.6 (2B), J9.6
unnamed: A3.16 (DIR), J23.2
unnamed: A3.10 (MS1), J15.2
unnamed: A3.11 (MS2), J16.2
unnamed: A3.15 (STEP), J23.1
unnamed: A3.9 (~ENABLE), J23.3
unnamed: A4.4 (1A), J8.3
unnamed: A4.3 (1B), J8.1
unnamed: A4.5 (2A), J8.4
unnamed: A4.6 (2B), J8.6
unnamed: A4.16 (DIR), J22.2
unnamed: A4.10 (MS1), J17.2
unnamed: A4.11 (MS2), J18.2
unnamed: A4.15 (STEP), J22.1
unnamed: A4.9 (~ENABLE), J22.3
unnamed: D1.2 (A), R1.2
unnamed: D2.2 (A), R2.2
actio_+6V: J2.4, J31.1, J31.2, J31.3, J31.4

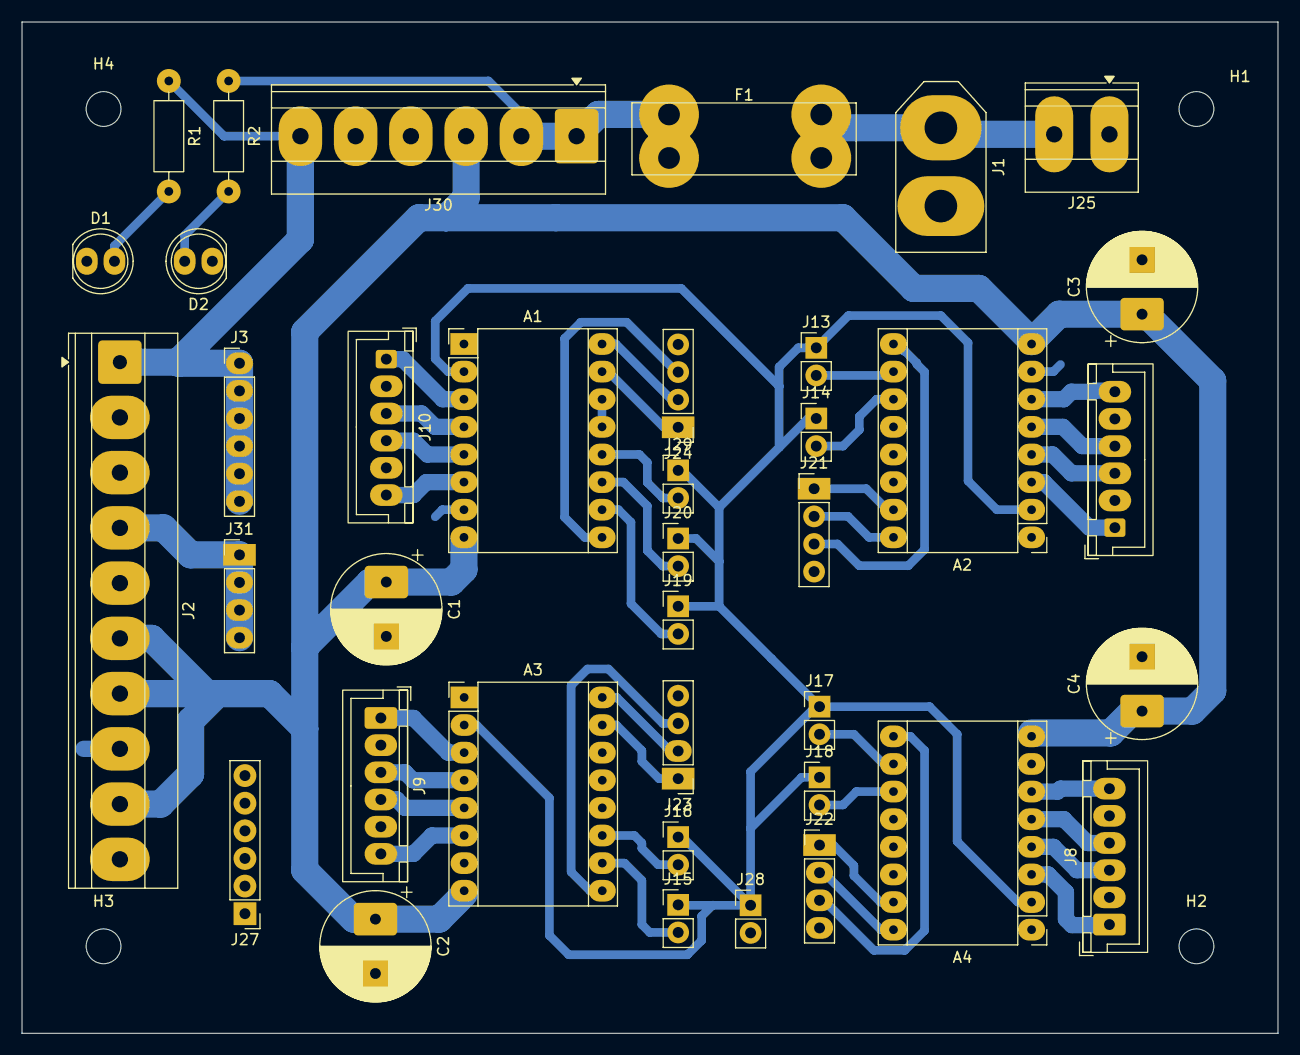
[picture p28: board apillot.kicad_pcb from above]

Board: 2 copper layers, 115.5 x 93.0 mm, 42 parts (0 on the bottom side), 47 nets.

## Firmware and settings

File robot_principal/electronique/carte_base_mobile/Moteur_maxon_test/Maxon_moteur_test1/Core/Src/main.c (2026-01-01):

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
/* Includes ------------------------------------------------------------------*/
#include "main.h"

DAC_HandleTypeDef hdac1;

UART_HandleTypeDef huart2;

/* USER CODE BEGIN PV */
int32_t vitesse_moteur = 0;
int cpt = 0;
/* USER CODE END PV */

void SystemClock_Config(void);
static void MX_GPIO_Init(void);
static void MX_USART2_UART_Init(void);
static void MX_DAC1_Init(void);
/**
  * @brief  The application entry point.
  * @retval int
  */
int main(void)
{

  /* MCU Configuration--------------------------------------------------------*/

  /* Reset of all peripherals, Initializes the Flash interface and the Systick. */
  HAL_Init();

  /* Configure the system clock */
  SystemClock_Config();

  /* Initialize all configured peripherals */
  MX_GPIO_Init();
  MX_USART2_UART_Init();
  MX_DAC1_Init();
  /* USER CODE BEGIN 2 */
  HAL_DAC_Start(&hdac1, DAC_CHANNEL_1);   // UNE SEULE FOIS
  HAL_DAC_SetValue(&hdac1, DAC_CHANNEL_1, DAC_ALIGN_12B_R, vitesse_moteur);  //1.5v (1.5 * 3.3)/4095

  HAL_GPIO_WritePin(GPIOB, enable_Pin, GPIO_PIN_RESET);  //desactive moteur
  /* USER CODE END 2 */

  /* Infinite loop */
  /* USER CODE BEGIN WHILE */
  while (1)
  {
	  /* Lire l’état du bouton USER pour arreter moteur*/
	 if(HAL_GPIO_ReadPin(GPIOC, B1_Pin) == GPIO_PIN_RESET) // bouton appuyé
	 {
		 HAL_GPIO_TogglePin(GPIOA, LD2_Pin);
		 HAL_GPIO_TogglePin(GPIOB, enable_Pin); // active ou désactive le moteur

		 HAL_Delay(500);
	 }

	 /* Lire l’état du bouton USER pour changer de direction*/
	 if(HAL_GPIO_ReadPin(GPIOA, choix_direction_Pin) == GPIO_PIN_RESET) // bouton appuyé
	 {
		 HAL_GPIO_TogglePin(GPIOA, LD2_Pin);
		 HAL_GPIO_TogglePin(GPIOB, direction_Pin); // change le sens du moteur
		 HAL_Delay(500);
	 }

	 /* Lire l’état du bouton USER pour changer de vitesse*/
	 if(HAL_GPIO_ReadPin(GPIOA, change_vitesse_Pin) == GPIO_PIN_RESET) // bouton appuyé
	 {
		 HAL_GPIO_TogglePin(GPIOA, LD2_Pin);
		 cpt++;
		 if (cpt == 1 ) vitesse_moteur = ((1/3.3) * 4095);
		 else if (cpt == 2 ) vitesse_moteur = ((1.5/3.3) * 4095);
		 else if (cpt == 3 ) vitesse_moteur = ((2/3.3) * 4095);
		 else if (cpt == 4 ) vitesse_moteur = ((2.5/3.3) * 4095);
		 else if (cpt == 5 ) vitesse_moteur = ((3/3.3) * 4095);
		 else if (cpt == 6 ) vitesse_moteur = ((3.3/3.3) * 4095);
		 else if (cpt == 7) {vitesse_moteur = 0;cpt = 0;}

		 HAL_DAC_SetValue(&hdac1, DAC_CHANNEL_1, DAC_ALIGN_12B_R, vitesse_moteur);  //1.5v (1.5 * 3.3)/4095
		 HAL_Delay(500);
	 }

    /* USER CODE END WHILE */

    /* USER CODE BEGIN 3 */
  }
  /* USER CODE END 3 */
}

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


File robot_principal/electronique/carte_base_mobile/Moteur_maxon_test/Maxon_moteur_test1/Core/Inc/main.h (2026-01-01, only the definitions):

#define B1_Pin GPIO_PIN_13
#define B1_GPIO_Port GPIOC
#define USART_TX_Pin GPIO_PIN_2
#define USART_TX_GPIO_Port GPIOA
#define USART_RX_Pin GPIO_PIN_3
#define USART_RX_GPIO_Port GPIOA
#define vitesse_Pin GPIO_PIN_4
#define vitesse_GPIO_Port GPIOA
#define LD2_Pin GPIO_PIN_5
#define LD2_GPIO_Port GPIOA
#define choix_direction_Pin GPIO_PIN_8
#define choix_direction_GPIO_Port GPIOA
#define change_vitesse_Pin GPIO_PIN_10
#define change_vitesse_GPIO_Port GPIOA
#define TMS_Pin GPIO_PIN_13
#define TMS_GPIO_Port GPIOA
#define TCK_Pin GPIO_PIN_14
#define TCK_GPIO_Port GPIOA
#define SWO_Pin GPIO_PIN_3
#define SWO_GPIO_Port GPIOB
#define enable_Pin GPIO_PIN_4
#define enable_GPIO_Port GPIOB
#define direction_Pin GPIO_PIN_5
#define direction_GPIO_Port GPIOB

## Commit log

2025-12-19 Ajout des fichiers de documentations
2025-12-22 Ajout d'un dossier pour les datasheets des composants
2025-12-30 ajout de la datasheet du controleur escon 50/5
2025-12-30 ajout fichier pour le moteur maxon
    le fichier contenant les parametres du logiciel escon studio 2.2 (windows only) pour le controler d'un moteur maxon avec un réducteur de 100. et aussi de la capture d'écran des résultat du test de co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
2025-12-31 Ajout des datasheets pour les STM32
2026-01-01 Ajout du code de test pour le moteur maxon avec la carte stm32 (Nucleo L476RG)
2026-01-07 Ajout d'un fichier pour le lancement de la raspberry avec le LIDAR
2026-01-08 modif du fichier de lien et ajout fichier pour le lidar et raspberry
2026-01-20 ajout fichier fonctionnement git, ajout de test lidar avec respberry
2026-02-11 Fix STEPS_TARGET calculation and add infinite loop to halt program after one rotation
    [main.cpp]
2026-02-26 ajout datasheet nucleo et debut PCB carte puissance
    [Carte_puissance.kicad_pcb, Carte_puissance.kicad_sch]
2026-03-10 carte elec de puissance terminée
    [Carte_puissance.kicad_pcb, Carte_puissance.kicad_sch]
2026-03-11 Carte elec fini, demande gravure faite
    [Carte_puissance-B_Cu.gbl, Carte_puissance-B_Mask.gbs, Carte_puissance-B_Paste.gbp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]

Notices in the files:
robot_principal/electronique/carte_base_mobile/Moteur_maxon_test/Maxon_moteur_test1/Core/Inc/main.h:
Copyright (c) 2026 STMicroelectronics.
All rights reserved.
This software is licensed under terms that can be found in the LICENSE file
